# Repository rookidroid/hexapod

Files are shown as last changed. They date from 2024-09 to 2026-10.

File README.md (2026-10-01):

#  Hexapod

A family of 18-DOF, 3D-printed hexapod robots powered by an ESP32. Walk them from your phone over WiFi, or stream poses to them live from a computer. All the robots run the same firmware and gait generator. What differs is their frame, servos and dimensions.





## The Robots

| | [Nougat](./robots/nougat/) | [Mochi](./robots/mochi/) | [Macaroon](./robots/macaroon/) |
|---|---|---|---|
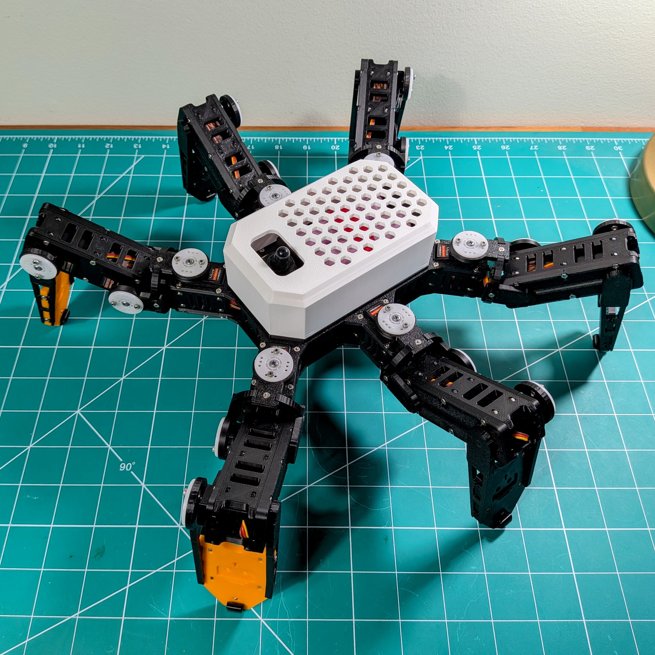
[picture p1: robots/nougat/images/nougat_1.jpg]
Nougat
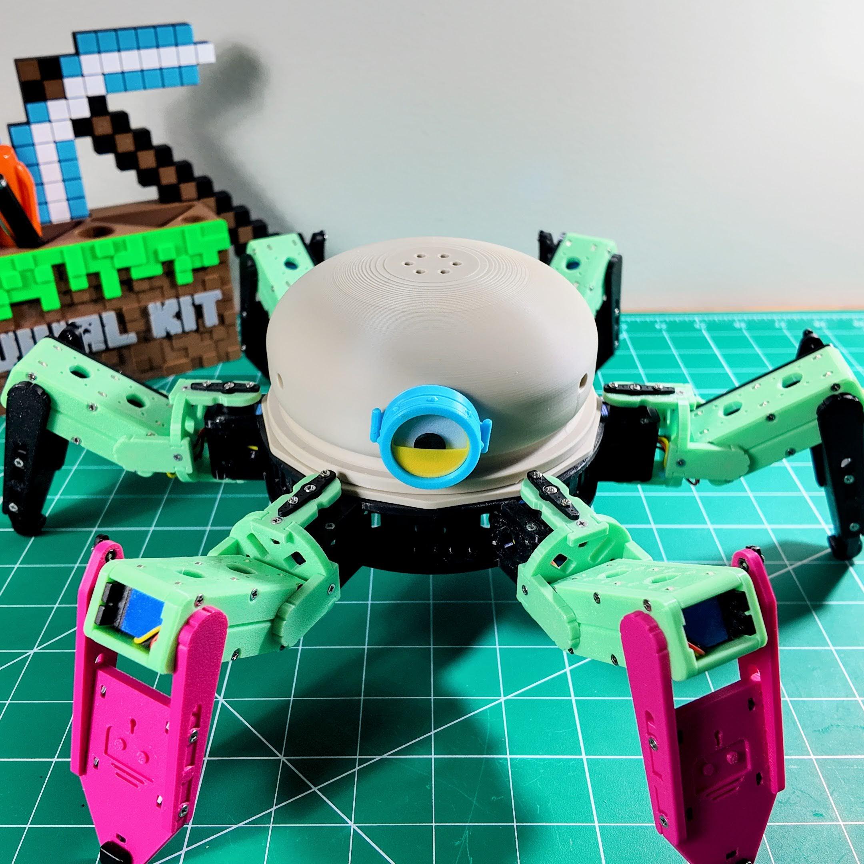
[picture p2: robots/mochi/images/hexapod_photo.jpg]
Mochi
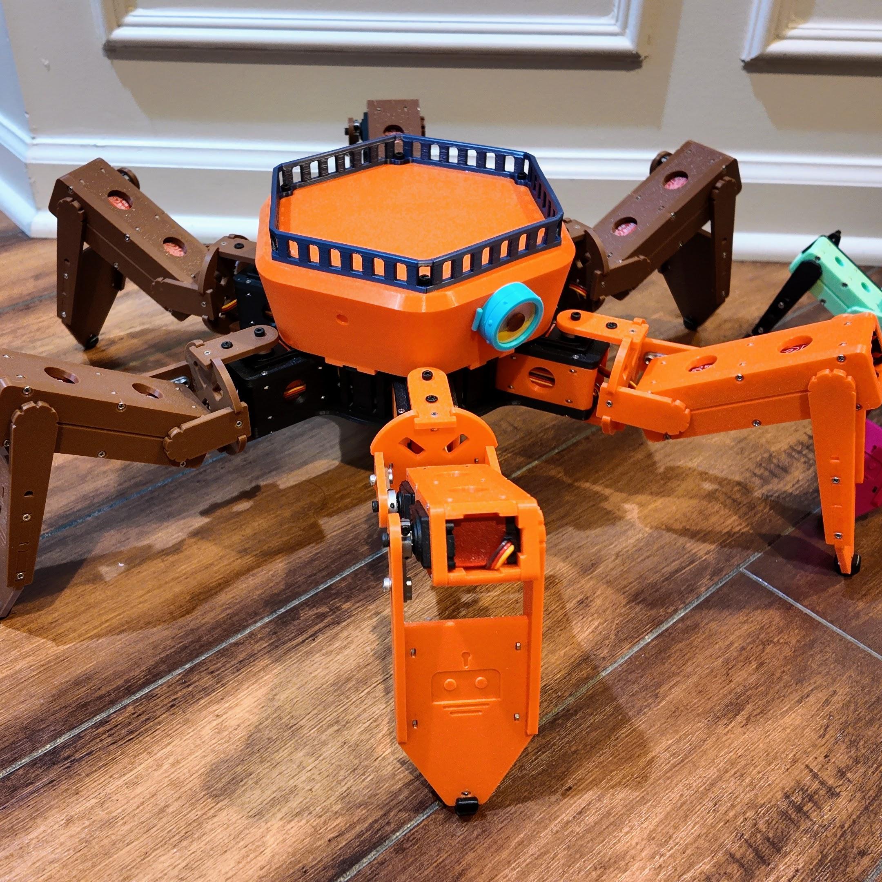
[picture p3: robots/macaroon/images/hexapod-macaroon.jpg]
Macaroon
| |  |  |  |
| **Servos** | 18 × 21G digital | 18 × MG92B micro | 18 × 25 kg digital |
| **Battery** | 2 × 18650 (2S1P) | 2 × 18650 (2S) | 4 × 18650 (2S2P) |
| **Leg links** (coxa / femur / tibia) | 38 / 54 / 97 mm | 36 / 44 / 85 mm | 62 / 76 / 132 mm |
| **Controller** | ESP32 (Pico W legacy) | ESP32 (Pico W legacy) | ESP32 |
| **Firmware define** | `ROBOT_NOUGAT` | `ROBOT_MOCHI` | `ROBOT_MACAROON` |
| **WiFi SSID** | `hexapod_nougat` | `hexapod` | `hexapod_macaroon` |

Each robot's folder has its full build guide: bill of materials, 3D-printed parts, assembly, software setup, calibration and troubleshooting.

## Repository Layout

```text
hexapod/
├── robots/                 # Hardware for each robot
│   ├── nougat/             #   README (build guide), 3d print/, images/
│   ├── mochi/
│   └── macaroon/
├── images/                 # Images shared by all robots
└── software/
    ├── hexapod_esp32/      # ESP32 firmware (Arduino sketch), shared by all robots
    │   ├── robot.h         #   Pick the robot you are building here
    │   └── src/robots/     #   Per-robot settings and generated motion tables
    ├── package_esp32.py    # Packages the ESP32 sketch into one copy per robot
    ├── hexapod_pico/       # Legacy Raspberry Pi Pico firmware (unmaintained)
    └── path_tool/          # Gait generator that produces the motion tables
        └── robots/         #   Per-robot geometry and gait parameters (JSON)
```

## Quick Start

1. Build the robot by following its guide in [`robots/`](./robots/).
2. Open [`software/hexapod_esp32/hexapod_esp32.ino`](./software/hexapod_esp32/hexapod_esp32.ino) in the Arduino IDE.
3. In [`robot.h`](./software/hexapod_esp32/robot.h), leave only your robot's `#define ROBOT_*` uncommented.
4. Upload, join the robot's WiFi network and calibrate it at `http://192.168.4.1`.

To skip step 3, download `hexapod_<robot>_<version>.zip` from the [releases](https://github.com/rookidroid/hexapod/releases): a copy of the sketch with your robot already selected. `python software/package_esp32.py` builds the same zips locally into `dist/`.

The [ESP32 firmware README](./software/hexapod_esp32/README.md) covers setup, the UDP protocol and OTA updates. The [path tool README](./software/path_tool/README.md) explains how the motion tables are generated and how to add a new robot.

## License

[GPL-3.0](./LICENSE)

## Support

- Website: [rookidroid.com](https://rookidroid.com/)
- Issues: [GitHub Issues](https://github.com/rookidroid/hexapod/issues)
- E-mail: [info@rookidroid.com](mailto:info@rookidroid.com)

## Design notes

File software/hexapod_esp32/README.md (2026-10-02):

# Hexapod ESP32 Firmware

Arduino-based firmware for the ESP32-powered hexapod robot controller, shared by every robot in the family ([Nougat](../../robots/nougat/), [Mochi](../../robots/mochi/) and [Macaroon](../../robots/macaroon/)). Supports WiFi control via UDP commands, OTA updates, and 18-servo coordination through dual PCA9685 PWM drivers.

## Features

- **WiFi Control**: Access Point mode with UDP command interface
- **Web Controller & Calibration**: Drive the robot from any browser, and adjust and save servo offsets to flash
- **Binary UDP Protocol**: Fast and efficient binary packet structure for motion control
- **18-Servo Control**: Dual PCA9685 PWM drivers (I2C) for coordinated leg movement
- **OTA Updates**: Wireless firmware updates over WiFi
- **Motion Library**: Pre-programmed gaits and movements
- **Non-blocking Motion Engine**: Gaits, streamed poses and every transition between them run from one tick-driven engine, so the web UI, OTA and failsafes stay responsive while walking
- **Event-Driven Boot**: Automatic boot sequence when client connects

## Hardware Requirements

- ESP32 Dev Module
- [Hexapod Controller Board (ESP32)](https://rookidroid.com/product/hexapod-controller-board-esp32/) - ESP32-based controller with dual PCA9685 PWM drivers
- 18× Servos (3 per leg × 6 legs)

## Dependencies

Install these libraries through Arduino Library Manager:

| Library | Purpose | Link |
|---|---|---|
| arduino-esp32 | ESP32 board support | [GitHub](https://github.com/espressif/arduino-esp32) |
| Adafruit_PWMServoDriver | PCA9685 control | [GitHub](https://github.com/adafruit/Adafruit-PWM-Servo-Driver-Library) |
| AsyncUDP | Non-blocking UDP | Included with arduino-esp32 |
| ArduinoOTA | OTA updates | Included with arduino-esp32 |
| Preferences | Calibration storage (NVS) | Included with arduino-esp32 |
| EEPROM | One-time import of older calibrations | Included with arduino-esp32 |
| WebServer | Calibration UI | Included with arduino-esp32 |

## Quick Start

### 1. Setup Arduino IDE

1. Install [Arduino IDE 2.x](https://www.arduino.cc/en/software)
2. Install ESP32 board support following [this guide](https://docs.espressif.com/projects/arduino-esp32/en/latest/installing.html)
3. Install required libraries via Library Manager (Sketch → Include Library → Manage Libraries)

### 2. Select Your Robot

Open `robot.h` and leave exactly one robot uncommented:

```cpp
// #define ROBOT_NOUGAT
// #define ROBOT_MOCHI
#define ROBOT_MACAROON
```

This picks the robot's motion tables and settings from `src/robots/<name>/`:

| Robot | `robot.h` define | WiFi SSID | `DELAY_MS` |
|---|---|---|---|
| Nougat | `ROBOT_NOUGAT` | `hexapod_nougat` | 12 |
| Mochi | `ROBOT_MOCHI` | `hexapod` | 12 |
| Macaroon | `ROBOT_MACAROON` | `hexapod_macaroon` | 25 |

`DELAY_MS` is the time between LUT frames. The frame period is now exactly
`DELAY_MS`: earlier firmware also spent ~10 ms per frame on a 100 kHz I2C bus,
so gaits play faster than before, most noticeably on Nougat and Mochi. Raise
`DELAY_MS` in `src/robots/<name>/robot_config.h` if a gait feels rushed.

With `arduino-cli`, you can pick the robot without editing the file:
`arduino-cli compile --fqbn esp32:esp32:esp32 --build-property "compiler.cpp.extra_flags=-DROBOT_MOCHI"`.

#### Per-robot packages

Each [GitHub release](https://github.com/rookidroid/hexapod/releases) also has
a ready-to-open sketch for every robot, `hexapod_<robot>_<version>.zip`. Unzip
it and open `hexapod_<robot>/hexapod_<robot>.ino`: `robot.h` is already set and
only that robot's tables are included, so you can skip this step.

To build the packages yourself, run `python software/package_esp32.py` from
the repository root. It writes a folder and a zip for every robot into `dist/`.
Name robots to package only those (`python software/package_esp32.py nougat`),
and pass `--no-zip` to write just the folders. Each package's `version.h` has
`FIRMWARE_BUILD` set to the package version (see [Firmware version](#firmware-version)).

### 3. Configure Hardware

Edit `config.h` if your wiring or WiFi password differs:

```cpp
// Servo pin mappings
static int left_legs[3][3] = { { 1, 2, 3 }, { 5, 6, 7 }, { 9, 8, 10 } };
static int right_legs[3][3] = { { 10, 9, 8 }, { 13, 14, 15 }, { 7, 6, 5 } };

// WiFi password (the SSID is set per robot in src/robots/<name>/robot_config.h)
#define APPSK "hexapod_1234"
```

### 4. Upload Firmware

1. Connect ESP32 via USB
2. Select **Tools → Board → ESP32 Dev Module**
3. Select correct COM port
4. Click **Upload**
5. Monitor Serial output (115200 baud) for IP address

### 5. Control the Robot

1. Connect to the robot's WiFi network (see the table above, password: `hexapod_1234`)
2. Robot will automatically perform boot sequence when client connects
3. Drive it from a browser at `http://192.168.4.1/` (see below), or send UDP commands to `192.168.4.1:1234`

## Drive from a Browser

The robot serves its own controller page, so a phone, tablet or laptop can drive
it with nothing installed.

1. Connect to the robot's WiFi network and open `http://192.168.4.1/`. The page
   opens on the **Drive** tab, a control panel that fills the whole window.
2. **Hold** to move, and slide your finger between zones without lifting it:
   - The **dial** (right) walks in eight directions on its inner ring. The outer
     ring does fast forward/backward at the top and bottom, and turns in place
     at the sides. The centre is Stop.
   - The **grid** (left) plays the body moves (rotate X/Y/Z, twist) and the
     climbing gait.
   - Let go and the robot settles back to standby.
3. On a keyboard, **W A S D** or the arrow keys walk (two at once for the
   diagonals), **Q** and **E** turn, and **Space** stops.
4. **Relax** cuts power to the servos so the robot sags to the ground. **Wake**,
   or any control, powers them again.

Landscape gives the Android app's layout, with the speed slider and buttons
between the two pads; in portrait they stack. Tap **Full screen** to hide the
browser bars on Android, iPad and desktop. iPhone Safari has no full-screen
mode: use **Share > Add to Home Screen** and open the page from the icon instead.

While a control is held the page resends the command every 150 ms over HTTP
(`POST /motion`), and the robot's usual 500 ms failsafe applies: if the phone
drops off the WiFi or the page goes to the background, the robot stops by
itself. The gait speed is sent with every move. Driving from the page and from
a UDP remote at the same time makes them fight over the robot; the last command
wins.

## How to Calibrate

The firmware includes a web-based calibration interface to easily adjust servo offsets without recompiling code. These offsets are saved to the ESP32's flash (NVS). Calibrations saved by older firmware in EEPROM are imported automatically on first boot.

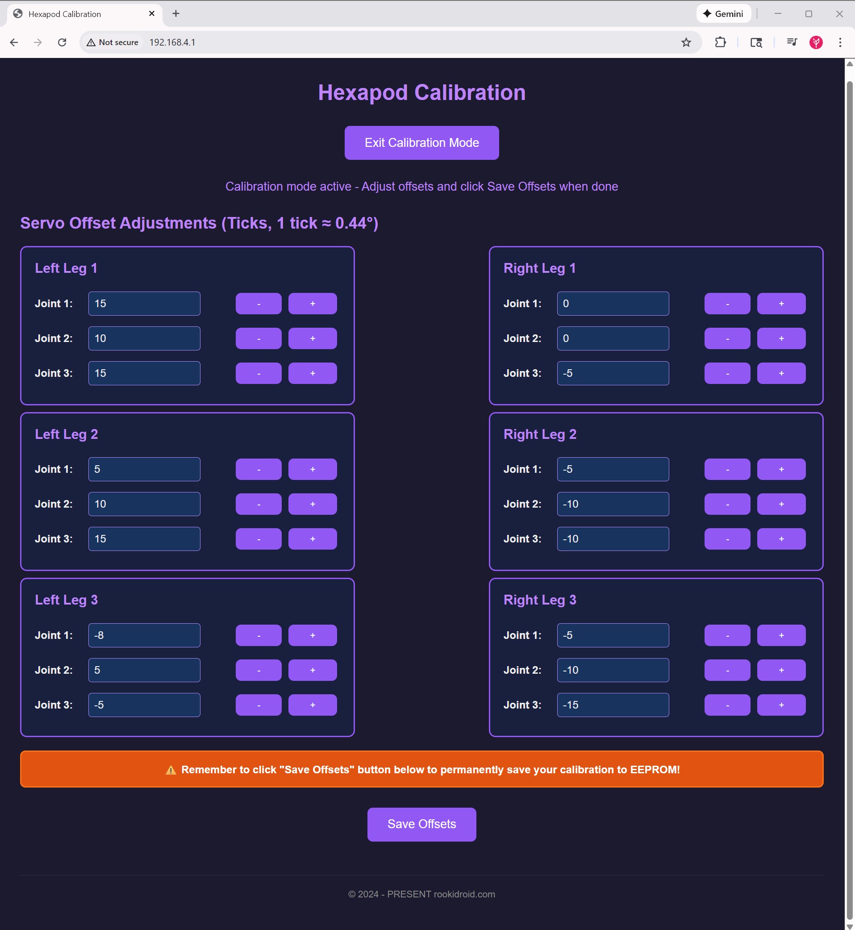
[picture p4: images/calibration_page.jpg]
Calibration Interface


### Calibration Steps:

1. Power on the hexapod and connect your device to its WiFi network (see [Select Your Robot](#2-select-your-robot)).
2. Open a web browser, navigate to `http://192.168.4.1/` and switch to the **Calibrate** tab.
3. Click the **Enter calibration** button. The robot will move to its neutral calibration posture.
4. Use the `+` and `-` buttons for each joint on the web interface to fine-tune the positions. Offsets are limited to ±100 ticks.
   - The goal is to align the legs such that the coxa (shoulder) is parallel to the body, the femur (thigh) is horizontal, and the tibia (calf) is vertical.
   - Adjust the offsets until all legs are perfectly aligned and the robot stands evenly.
5. Once satisfied with the posture, click **Save to robot**. This will permanently save the calibration values to flash.
6. Click **Exit**. The robot eases back to its standby posture.

*Note: You no longer need to manually edit offsets in `config.h`. If you wish to backup your offsets, the web interface will print the configured arrays to the Serial Monitor when you click save.*

## UDP Command Reference

Four binary packet types share port 1234. The **first byte selects the
protocol**, so the firmware dispatches on the magic number before it checks the
length (the motion and session packets are both 6 bytes).

| Magic | Packet | Size | Purpose |
|---|---|---|---|
| `0xA5` | Motion command | 6 or 7 B | Play one of the built-in gait LUTs, optionally at a set speed |
| `0xA6` | Real-time pose | 44 B | Stream raw servo positions for all 18 joints |
| `0xA7` | Session control | 6 B | Enter/leave real-time mode, relax, keep-alive |
| `0xA8` | Version query | 5 B | Ask for the firmware version; the robot replies |

All packets are little-endian and unpadded (`#pragma pack(1)`).

### Motion command (`0xA5`)

- **Byte 0**: Magic number (`0xA5`)
- **Byte 1**: Command ID (see enum below)
- **Bytes 2-5**: Sequence number (32-bit unsigned integer)
- **Byte 6** *(optional)*: Playback speed in percent (see [Motion speed](#motion-speed))

| Command ID | Action |
|---|---|
| 0 | Standby |
| 1 | Walk forward |
| 2 | Walk backward |
| 3-5 | Walk right (45°/90°/135°) |
| 6-8 | Walk left (45°/90°/135°) |
| 9-10 | Fast walk (forward/backward) |
| 11-12 | Rotate in place (left/right) |
| 13-14 | Climbing gait (forward/backward) |
| 15-17 | Body rotation (pitch/roll/yaw) |
| 18 | Body twist motion |

**Failsafe:** the robot returns to standby if no UDP packet arrives for 500 ms
(`MOTION_TIMEOUT_MS`), so keep resending the command while it should move.

Gaits change only at the start or midpoint of a cycle, and always pass through
the standby posture on the way to the next gait.

#### Motion speed

The 7-byte form appends a speed byte that sets how fast the gait LUTs play, as a
percentage of the robot's tuned frame rate (`DELAY_MS`). Values are clamped to
20-100 %; a gait at 50 % takes twice as long per cycle. The servos are still
updated every `DELAY_MS`: below 100 % the firmware blends between adjacent LUT
frames, so slow gaits stay smooth instead of stepping from frame to frame. `0`
leaves the speed unchanged, and the 6-byte form never
touches it. Only gait playback follows the speed: the transitions between gaits
keep their pace so the robot still stops promptly.

The speed starts at **60 %** after boot (`MOTION_SPEED_DEFAULT_PCT` in
`config.h`), so clients that only send the 6-byte form walk at 60 % unless the
speed is raised. It can also be set from the **Gait speed** slider on the web
page at `http://192.168.4.1/`; a client sending 7-byte packets, such as the
[arcade remote](https://github.com/rookidroid/remote-arcade), overrides it with
every packet. The setting is not saved across reboots.

#### Example (Python)

```python
import socket
import struct

# 0xA5 (magic), 1 (Walk forward), 0 (sequence), 60 (speed %)
packet = struct.pack("<BBIB", 0xA5, 1, 0, 60)
sock = socket.socket(socket.AF_INET, socket.SOCK_DGRAM)
sock.sendto(packet, ("192.168.4.1", 1234))
```

### Real-time pose (`0xA6`)

Streams servo positions directly, bypassing the motion LUTs. Used by the
[hexapod-robot-simulator](https://github.com/rookidroid/hexapod-robot-simulator)
to drive the robot live, from a single joint up to a whole-body pose.

| Offset | Type | Field | Notes |
|---|---|---|---|
| 0 | `uint8` | magic | `0xA6` |
| 1 | `uint8` | flags | bit 0: snap immediately instead of obeying the slew limit |
| 2 | `uint16` | max_step | Per-joint slew limit in ticks per 20 ms cycle (0 = default, 8) |
| 4 | `uint32` | seq_num | Sequence number |
| 8 | `int16[6][3]` | ticks | Servo ticks, leg-major |

Leg order matches the motion LUTs: right front, right middle, right back, left
front, left middle, left back. Joint order is coxa, femur, tibia. Ticks use the
same scale as the LUTs (`SERVOMIN` 102 … `SERVOMAX` 512, mid 307), before
calibration: the saved per-joint offset is added on the robot, exactly as it is
for LUT playback. Ticks are clamped on arrival to the window that stays within
`SERVOMIN`…`SERVOMAX` after that offset, so calibration never costs a joint any
travel.

Receiving a pose packet implicitly enters real-time mode from whatever posture
the robot holds, even mid-gait. Each control cycle every joint moves toward its
target by at most `max_step` ticks, so a large jump becomes a controlled slew
rather than a step input to 18 servos at once.

**Ordering:** UDP can reorder packets. A pose whose `seq_num` is up to 63 behind
the newest one received is dropped. A bigger step back is taken as a client
restart and accepted. The window resets on `RT_ENTER`.

**Failsafe:** if no packet arrives for 1 s the robot eases back to standby and
returns to LUT control. Send a keep-alive (below) while idle.

### Session control (`0xA7`)

| Offset | Type | Field |
|---|---|---|
| 0 | `uint8` | magic (`0xA7`) |
| 1 | `uint8` | action |
| 2 | `uint32` | seq_num |

| Action | Name | Effect |
|---|---|---|
| 0 | Exit | Leave real-time mode, resume LUT playback from standby |
| 1 | Enter | Enter real-time mode, holding the current posture |
| 2 | Relax | Disable both PWM drivers so the servos go limp; any motion command, pose or Enter wakes them |
| 3 | Ping | Keep-alive; resets the failsafe timer |

Sending a motion command (`0xA5`) also leaves real-time mode, so the two control
styles cannot fight over the servos.

#### Example (Python)

```python
import socket
import struct

sock = socket.socket(socket.AF_INET, socket.SOCK_DGRAM)
addr = ("192.168.4.1", 1234)

# Enter real-time mode
sock.sendto(struct.pack("<BBI", 0xA7, 1, 0), addr)

# Hold the standby posture (matches lut_standby)
ticks = [307, 239, 273] * 3 + [307, 375, 341] * 3
sock.sendto(struct.pack("<BBHI" + "h" * 18, 0xA6, 0, 8, 1, *ticks), addr)
```

### Version query (`0xA8`)

The only packet the robot answers. The reply goes back to the address and port
the query came from.

| Offset | Type | Field |
|---|---|---|
| 0 | `uint8` | magic (`0xA8`) |
| 1 | `uint32` | seq_num |

Reply (9-byte header, then the build tag):

| Offset | Type | Field | Notes |
|---|---|---|---|
| 0 | `uint8` | magic | `0xA8` |
| 1 | `uint32` | seq_num | Copied from the query |
| 5 | `uint8` | protocol | `PROTOCOL_VERSION` in `protocol.h` |
| 6 | `uint8` | major | Firmware version, see [Firmware version](#firmware-version) |
| 7 | `uint8` | minor | |
| 8 | `uint8` | patch | |
| 9 | `char[]` | build | `FIRMWARE_BUILD`, UTF-8, unterminated; runs to the end of the datagram |

A query is not control input: it does not reset the motion or real-time
failsafe timers and does not disable OTA. Firmware older than this packet does
not answer, so use a receive timeout and treat silence as "unknown version".

```python
import socket
import struct

sock = socket.socket(socket.AF_INET, socket.SOCK_DGRAM)
sock.settimeout(0.5)
sock.sendto(struct.pack("<BI", 0xA8, 7), ("192.168.4.1", 1234))

data, _ = sock.recvfrom(64)
magic, seq, protocol, major, minor, patch = struct.unpack_from("<BIBBBB", data)
print(f"firmware {major}.{minor}.{patch} ({data[9:].decode()}), protocol {protocol}")
```

> **Note:** packets are not echoed or logged to serial by default. Build with
> `HEXAPOD_DEBUG` set to 1 in `config.h` to log and echo motion and session
> packets. Pose packets are never logged: at 50 Hz the logging would saturate
> the serial port and stall the UDP task.

## Robot Config (HTTP)

`GET http://192.168.4.1/robot_config` describes the robot the firmware was built
for, so a client such as [Hexapod Link](https://github.com/rookidroid/hexapod-link)
can model and drive it without its own copy of every robot's config:

```json
{
  "protocol": 1,
  "firmware": {"version": "3.2.0", "build": "v3.2.0"},
  "name": "nougat",
  "ssid": "hexapod_nougat",
  "delay_ms": 12,
  "servo": {"min": 102, "mid": 307, "max": 512},
  "speed": {"min": 20, "max": 100, "default": 60, "current": 60},
  "commands": ["standby", "walk0", "walk180", "...", "twist"],
  "geometry": {"name": "nougat", "label": "Nougat", "legMountX": ["..."], "...": "..."}
}
```

- `protocol` is `PROTOCOL_VERSION` in `protocol.h`.
- `firmware` is the [firmware version](#firmware-version) and build tag.
- `commands` lists the motion names in `RobotCommand` order: a name's index is
  the command ID for a `0xA5` packet.
- `geometry` is the robot's `software/path_tool/robots/<name>.json` (leg mounts,
  link lengths, `legScale`, postures, gait radii and joint limits), compiled in
  from `src/robots/<name>/robot_geometry.h`. After editing the JSON, refresh the
  header with `python generate_motion.py <name>` (or `--geometry-only` to leave
  the LUTs alone).

The other HTTP routes back the web page's drive and calibration tabs:

| Route | Method | Purpose |
| --- | --- | --- |
| `/enter_calibration` | GET | Enter calibration mode; returns the offsets |
| `/exit_calibration` | GET | Leave calibration mode |
| `/get_offsets` | GET | `{"left":[[..],[..],[..]],"right":[[..],[..],[..]]}` |
| `/set_offsets` | POST | Apply offsets (same JSON; calibration mode only, each clamped to +/-100) |
| `/save_offsets` | POST | Save the offsets to flash |
| `/get_speed` | GET | `{"speed":N}` |
| `/set_speed?pct=N` | POST | Set the LUT playback speed; returns `{"speed":N}` |
| `/motion?id=N[&pct=S]` | POST | Play motion `N` (index into `commands`), optionally at speed `S`; same effect and 500 ms failsafe as a `0xA5` packet. Returns `{"motion":N,"speed":S}`; 409 in calibration mode |
| `/relax` | POST | Cut PWM drive so the servos go limp, like session action Relax; 409 in calibration mode |

## Firmware Version

`version.h` holds the firmware version, `FIRMWARE_VERSION_MAJOR`, `_MINOR` and
`_PATCH`. Bump it by hand when releasing: major for changes that break clients
or saved calibrations, minor for new features, patch for fixes and tuning.
`FIRMWARE_BUILD` is a free-form tag, `"dev"` in the repository; the release
packages set it to the package version (the git tag, or `git describe`).

The version is printed on the serial port at boot, returned by the
[version query](#version-query-0xa8) and included in `GET /robot_config`.

## OTA Updates

After initial USB upload, use OTA for wireless updates:

1. Power on robot and connect to its WiFi
2. In Arduino IDE: **Tools → Port → Network Ports**, then select `hexapod-<robot>` (e.g. `hexapod-macaroon`)
3. Upload as normal. The servos go limp while the new firmware is written
4. Note: OTA is disabled after the first motion command or real-time session (reboot to re-enable)

OTA has no password by default, so anyone who joins the robot's access point
can flash it. Define `OTA_PASSWORD` in `config.h` to require one.

## File Structure

```text
hexapod_esp32/
├── hexapod_esp32.ino    # setup() / loop() and the shared system state
├── motion_control.ino   # PWM drivers, motion engine, every write to a servo
├── realtime.ino         # Real-time pose streaming and its slew limiter
├── network.ino          # WiFi AP, OTA, UDP endpoint and packet parsing
├── calibration.ino      # Servo offsets loaded from / saved to flash (NVS)
├── web_ui.ino           # HTTP routes: drive, calibration, speed, /robot_config
├── hexapod.h            # Shared state and module interfaces
├── protocol.h           # UDP packet layouts and magic numbers
├── version.h            # Firmware version and build tag
├── web_page.h           # Drive and calibration page served from flash
├── config.h             # Hardware config, pin mappings, calibration
├── robot.h              # Selects the robot the firmware is built for
├── motion.h             # Includes the selected robot's motion tables
├── robot_geometry.h     # Includes the selected robot's geometry JSON
├── src/robots/<name>/
│   ├── robot_config.h   # Robot-specific settings (WiFi SSID, DELAY_MS)
│   ├── robot_geometry.h # Geometry served at /robot_config (generated by path_tool)
│   └── motion.h         # Motion lookup tables (generated by path_tool)
└── README.md            # This file
```

[`../package_esp32.py`](../package_esp32.py) copies this sketch into one
`hexapod_<robot>/` sketch per robot (see [Per-robot packages](#per-robot-packages)).

The `.ino` files are Arduino sketch tabs: the build concatenates them into one
translation unit, so the `static` tables in `config.h` and `motion.h` exist once
and every module sees the same calibration offsets. Types used in function
signatures belong in `hexapod.h`, because the build hoists each tab's function
prototypes above that tab's own declarations.

Only the main loop writes to the servos. The UDP task records requests
(`next_motion_idx`, `realtime_mode`, `relax_requested`, the streamed pose) and
`serviceMotionEngine()` acts on them at its next tick, starting every transition
from `pose_current`, the pose last written to the servos.

## Configuration Parameters

Key constants in `config.h`:

```cpp
// Servo timing (DELAY_MS, the delay between LUT steps, is per robot in robot_config.h)
const uint16_t SERVO_INIT_DELAY_MS = 50;    // Boot sequence delay
const uint8_t TRANSITION_TICK_STEP = 6;      // Transition smoothness
#define MOTION_TIMEOUT_MS 500                // LUT failsafe
#define REALTIME_TIMEOUT_MS 1000             // Real-time failsafe

// Hardware
const uint8_t LEFT_PWM_ADDRESS = 0x40;       // Left PCA9685 I2C address
const uint8_t RIGHT_PWM_ADDRESS = 0x41;      // Right PCA9685 I2C address
const uint8_t LEFT_PWM_ENABLE_PIN = 19;      // Left driver enable (active LOW)
const uint8_t RIGHT_PWM_ENABLE_PIN = 26;     // Right driver enable (active LOW)
const uint32_t I2C_CLOCK_HZ = 400000;        // I2C bus speed
const uint32_t PCA9685_OSC_HZ = 25000000;    // Tune if servo angles are off

// Calibration
const int CALIBRATION_MAX_OFFSET = 100;      // Largest accepted offset (ticks)
```

## Troubleshooting

### WiFi connection issues

- Verify the SSID in `src/robots/<name>/robot_config.h` and the password in `config.h`
- Check serial monitor for IP address (192.168.4.1 default)
- Ensure client device supports 2.4GHz WiFi

### Servos not moving

- Check PWM driver I2C addresses match hardware (0x40, 0x41)
- Verify enable pins are connected correctly (active LOW)
- Confirm servo pin mappings in `config.h`
- Test individual servos with `posture_calibration()` function

### OTA not visible

- OTA only works before first motion command
- Reboot robot to re-enable OTA
- Ensure connected to robot's WiFi network
- Check firewall settings on upload computer

## Adding Custom Motions

1. Add the path to `gen_luts()` in [`../path_tool/generate_motion.py`](../path_tool/generate_motion.py) so it is generated for every robot
2. Regenerate the LUTs with `python generate_motion.py --all`, which rewrites each `src/robots/<name>/motion.h`
3. Add a command ID before `CMD_COUNT` in `protocol.h`, then the matching entry at the same position in `motion_config[]` in `motion_control.ino` (a `static_assert` checks the counts match):

```cpp
const MotionConfig motion_config[] = {
  // ... existing motions ...
  { "mymotion", lut_mymotion_length, lut_mymotion }
};
```

## License

Copyright (C) 2024 - PRESENT rookidroid.com

## Support

- Website: [rookidroid.com](https://rookidroid.com/)
- Email: [info@rookidroid.com](mailto:info@rookidroid.com)

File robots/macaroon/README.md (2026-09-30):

#  Hexapod Macaroon

An 18-DOF, 3D-printed hexapod robot powered by an ESP32 — walk it from your phone over WiFi, or stream poses to it live from a computer.





hexapod_photo1
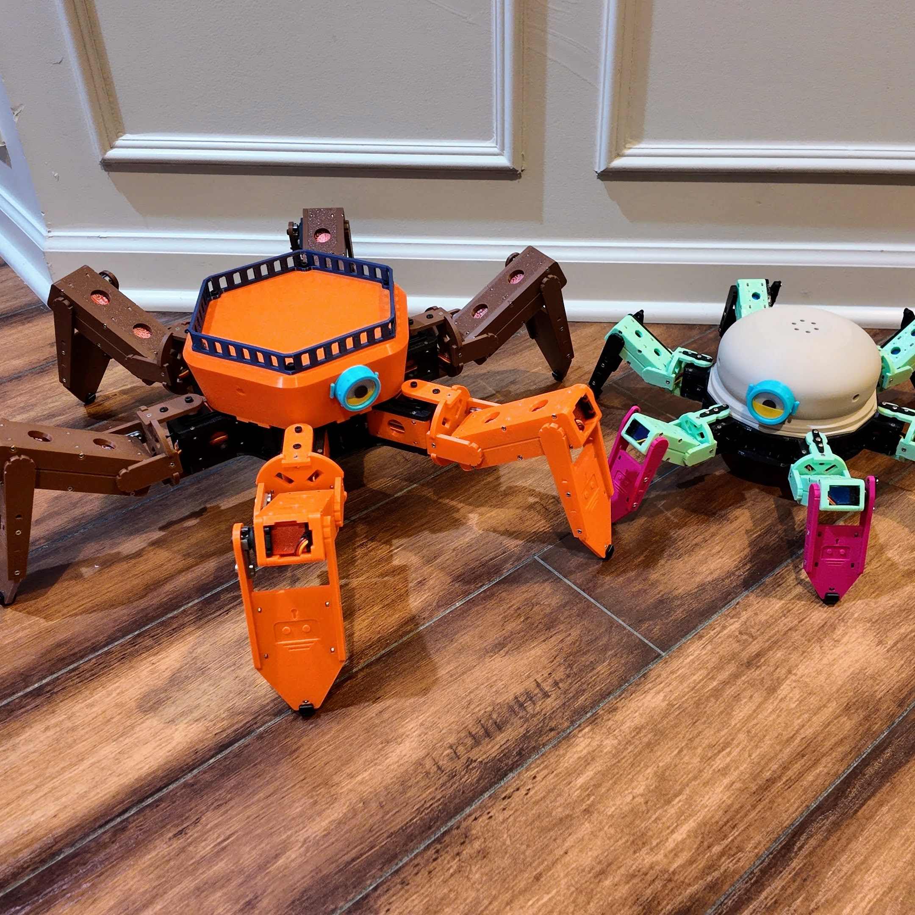
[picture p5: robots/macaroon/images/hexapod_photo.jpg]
hexapod_photo2


**Jump to:** [Bill of Materials](#bill-of-materials-bom) · [Assembly](#assembly-instructions) · [Software Setup](#software-setup) · [Control Interface](#control-interface) · [Calibration](#calibration-guide) · [Troubleshooting](#troubleshooting)

<details>
<summary><b>Table of Contents</b></summary>

- [Introduction](#introduction)
  - [Specifications](#specifications)
  - [What You'll Build](#what-youll-build)
  - [Skill Level](#skill-level)
- [Bill of Materials (BOM)](#bill-of-materials-bom)
  - [Electronics Components](#electronics-components)
  - [Connection Diagram](#connection-diagram)
- [Assembly Instructions](#assembly-instructions)
  - [Safety Notes](#safety-notes)
  - [Step 1: 3D-Printed Parts](#step-1-3d-printed-parts)
  - [Step 2: Hardware Components](#step-2-hardware-components)
- [Software Setup](#software-setup)
  - [Prerequisites](#prerequisites)
  - [Step-by-Step Installation](#step-by-step-installation)
  - [Repository Layout](#repository-layout)
  - [Project File Structure](#project-file-structure)
  - [Regenerating the Motion Tables](#regenerating-the-motion-tables)
  - [Control Interface](#control-interface)
  - [Over-The-Air (OTA) Updates](#over-the-air-ota-updates)
  - [Troubleshooting](#troubleshooting)
  - [Android App](#android-app)
  - [Desktop Control Software](#desktop-control-software)
- [Calibration Guide](#calibration-guide)
- [Related Projects](#related-projects)
- [Contributing](#contributing)
- [License](#license)
- [Support](#support)

</details>

## Introduction

This agile, 3D-printed hexapod robot is designed to work with an ESP32, providing flexibility and enhanced performance. Equipped with stronger 25kg servos, it offers a range of advanced features, including:

- **Robust, durable structure**: 3D-printed parts designed for strength and easy assembly
- **WiFi-enabled remote control**: Control your hexapod wirelessly from your smartphone or computer
- **Smooth, agile movement**: Advanced motion algorithms for natural walking patterns
- **Web-based calibration interface**: Easy servo calibration through your browser with real-time adjustment
- **Real-time pose streaming**: Drive all 18 servos live from a computer over UDP
- **Over-the-air (OTA) firmware updates**: Update firmware without cables for easy maintenance

### Specifications

| Item | Value |
| ---- | ----- |
| **Degrees of freedom** | 18 (6 legs × 3 joints: coxa, femur, tibia) |
| **Actuators** | 18 × 25 kg digital servos, 180° travel, 8.4 V capable |
| **Controller** | ESP32 with dual PCA9685 PWM drivers (I²C `0x40` / `0x41`) |
| **Power** | 4 × 18650 Li-ion in 2S2P — 7.4 V nominal, 8.4 V fully charged |
| **Connectivity** | 2.4 GHz WiFi Access Point (the robot hosts its own network) |
| **Control** | Binary UDP protocol on `192.168.4.1:1234`, plus a web UI on `http://192.168.4.1` |
| **Real-time streaming** | All 18 joints at 50 Hz, with per-joint slew limiting and a 1 s failsafe |
| **Firmware updates** | USB or over-the-air (OTA) over WiFi |
| **Resolution** | ~0.44° per servo tick (410 ticks over 180°) |

### What You'll Build

This project will guide you through building a fully functional hexapod robot with 18 degrees of freedom (3 joints per leg × 6 legs). The complete build typically takes 8-12 hours, including 3D printing, assembly, and calibration.

### Skill Level

- **Beginner-Intermediate**: Mechanical assembly skills required. No soldering is needed with the pre-assembled [Controller Board](https://rookidroid.com/product/hexapod-controller-board-macaroon-esp32/) — the servos, switch and battery holder plug straight in.
- **Tools needed**: Hex key set and a small screwdriver
- **Only if you build your own wiring harness**: soldering iron, wire cutters/strippers

## Bill of Materials (BOM)

### Electronics Components

| Name | Thumbnail | Required # | Specifications | Note |
| --- | --- | --- | --- | --- |
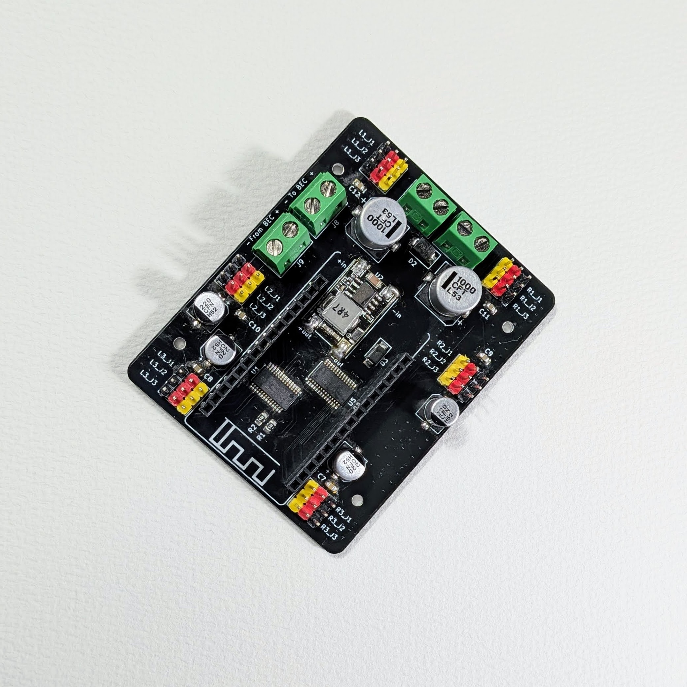
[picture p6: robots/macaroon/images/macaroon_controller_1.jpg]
controller_board
| Controller Board |  | 1 | ESP32 with dual PCA9685 drivers; servos are powered directly from the batteries | Purchase [Controller Board](https://rookidroid.com/product/hexapod-controller-board-macaroon-esp32/). |
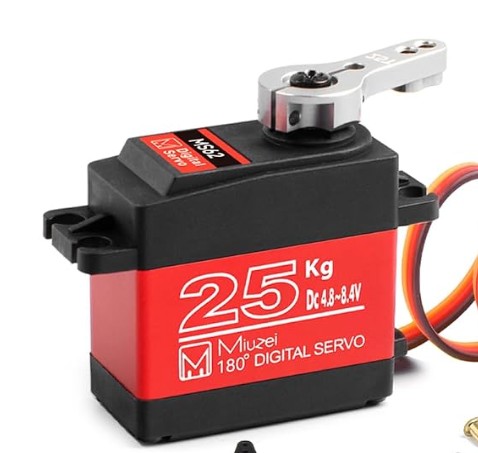
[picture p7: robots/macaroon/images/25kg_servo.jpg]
25kg_servo
| 25 kg Servo |  | 18 | 180° rotation, 25 kg class | **Support 8.4v supply voltage**. Ensure all servos are from the same batch for consistency |
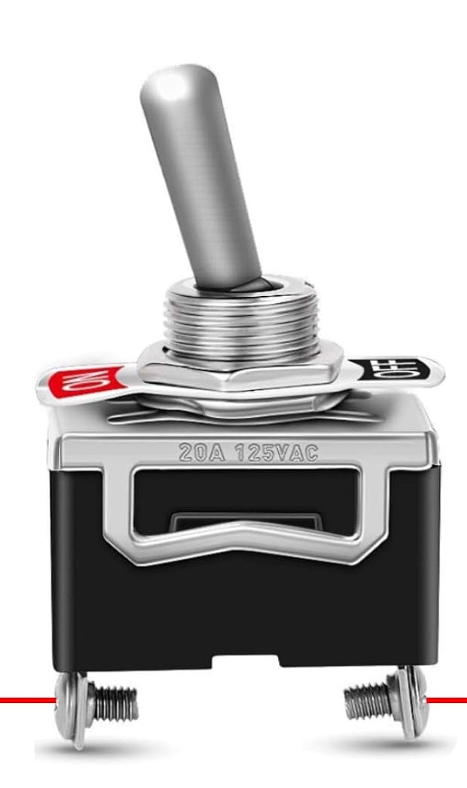
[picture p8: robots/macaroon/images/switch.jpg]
switch
| Toggle Switch |  | 1 | SPST, 12 mm diameter |  Purchase together with the [Controller Board](https://rookidroid.com/product/hexapod-controller-board-macaroon-esp32/). |
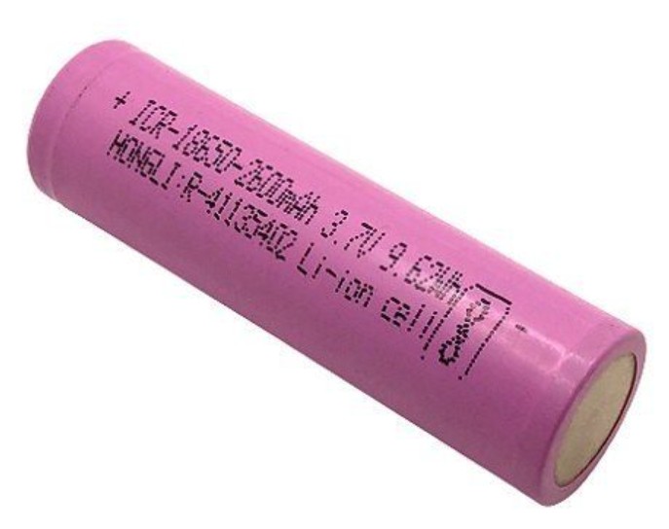
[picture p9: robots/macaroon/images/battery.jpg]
battery
| 18650 Battery |  | 4 | 3.7V Li-ion, 2000mAh+ recommended | **Use protected batteries for safety** |
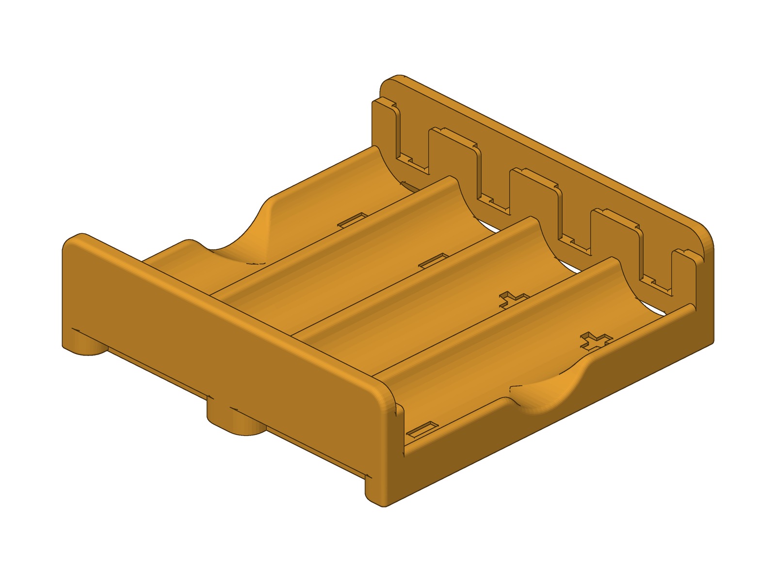
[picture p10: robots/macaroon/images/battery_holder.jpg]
battery_holder
| 18650 Battery Holder |  | 1 | 4-cell (2S2P) holder with wire leads | A 3D-printable holder is available [here](https://rookidroid.com/product/18650-battery-holder/), or purchase together with the [Controller Board](https://rookidroid.com/product/hexapod-controller-board-macaroon-esp32/). |

### Connection Diagram

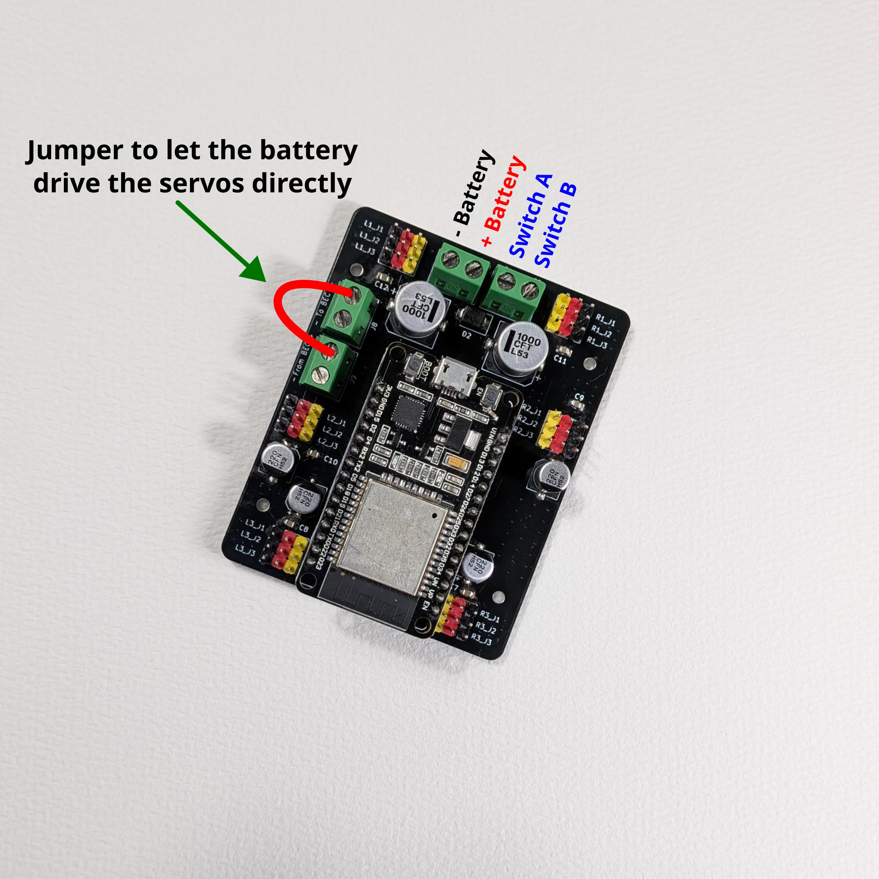
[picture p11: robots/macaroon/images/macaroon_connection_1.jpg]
diagram_1


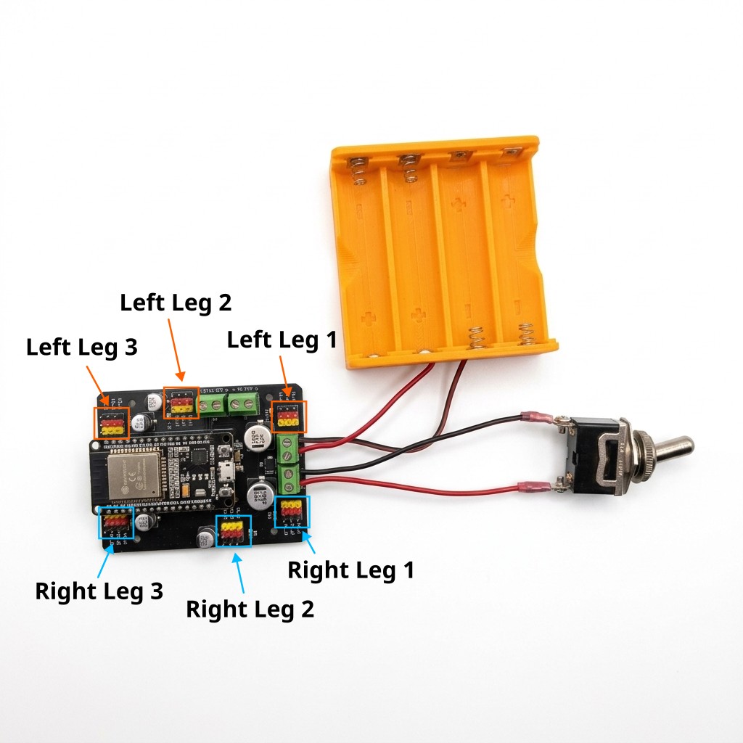
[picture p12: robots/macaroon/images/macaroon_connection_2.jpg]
diagram_2


## Assembly Instructions

### Overview

Follow these steps in order for the best results:

1. **3D Print all parts** (see parts list below)
2. **Prepare hardware** (organize screws, nuts, bearings, and pins)
3. **Assemble body** (install servos and controller)
4. **Build legs** (joint → leg → foot for each leg)
5. **Attach legs to body**
6. **Wire and test** (connect servos, upload firmware, calibrate)

**⚠️ Important:** Do NOT tighten the servo horn screws during assembly! Leave them loose to allow for rotation. You'll tighten them properly during the calibration process after adjusting each servo to its correct neutral position.

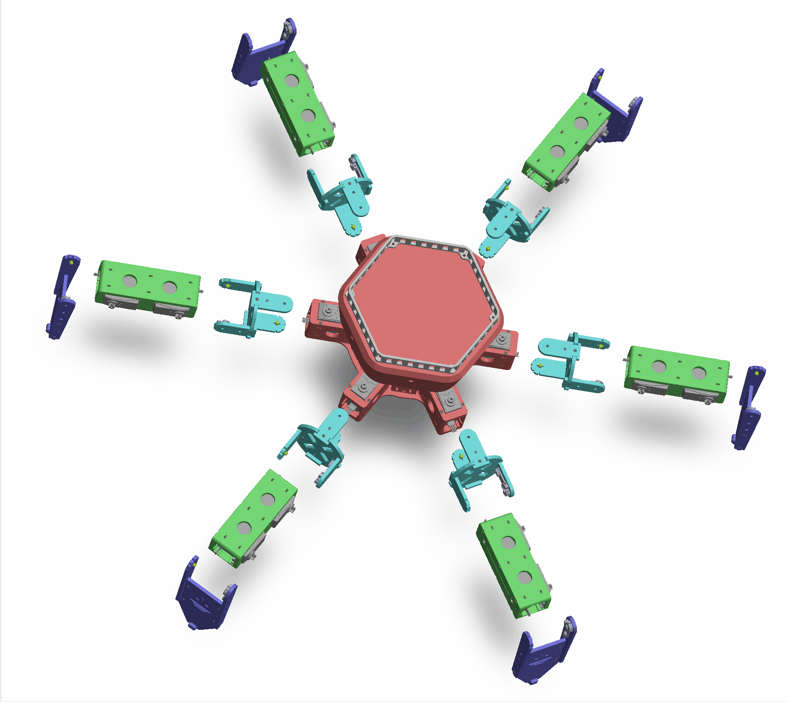
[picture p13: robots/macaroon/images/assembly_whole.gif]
whole_assembly


### Safety Notes

- **Check battery polarity twice** before the first power-up — reversed polarity will destroy the controller board.
- **Keep fingers clear of the joints when powered.** Eighteen 25 kg servos have enough torque to pinch hard.
- **Support the robot on the first power-on.** It runs its stand-up sequence automatically as soon as a client joins its WiFi network, so hold it or stand it on a box with the legs free.
- **Treat the Li-ion pack with respect**: protected cells only, a proper 2S charger, and never charge unattended.
- If a leg moves somewhere unexpected, **cut power with the toggle switch** rather than trying to hold the leg back.

### Step 1: 3D-Printed Parts

All STL files are located in the [`3d print`](./3d%20print/) folder. Ready-to-print Bambu Studio projects (`bambu_studio_*.3mf`) are included as well.

**Print Settings Recommendations:**

- Layer height: 0.2 mm
- Infill: 20-30%
- Material: PLA or PETG for the structure, TPU for the foot tips
- Supports: Required for some parts (check STL orientation)
- Print one leg's worth of parts first and test-fit it before committing to all six

#### Step 1.1: Body Components (x1 complete body)

**Assembly Tips:**

- Install servos before closing the body
- Route wires neatly to avoid pinching
- Test fit all parts before final assembly

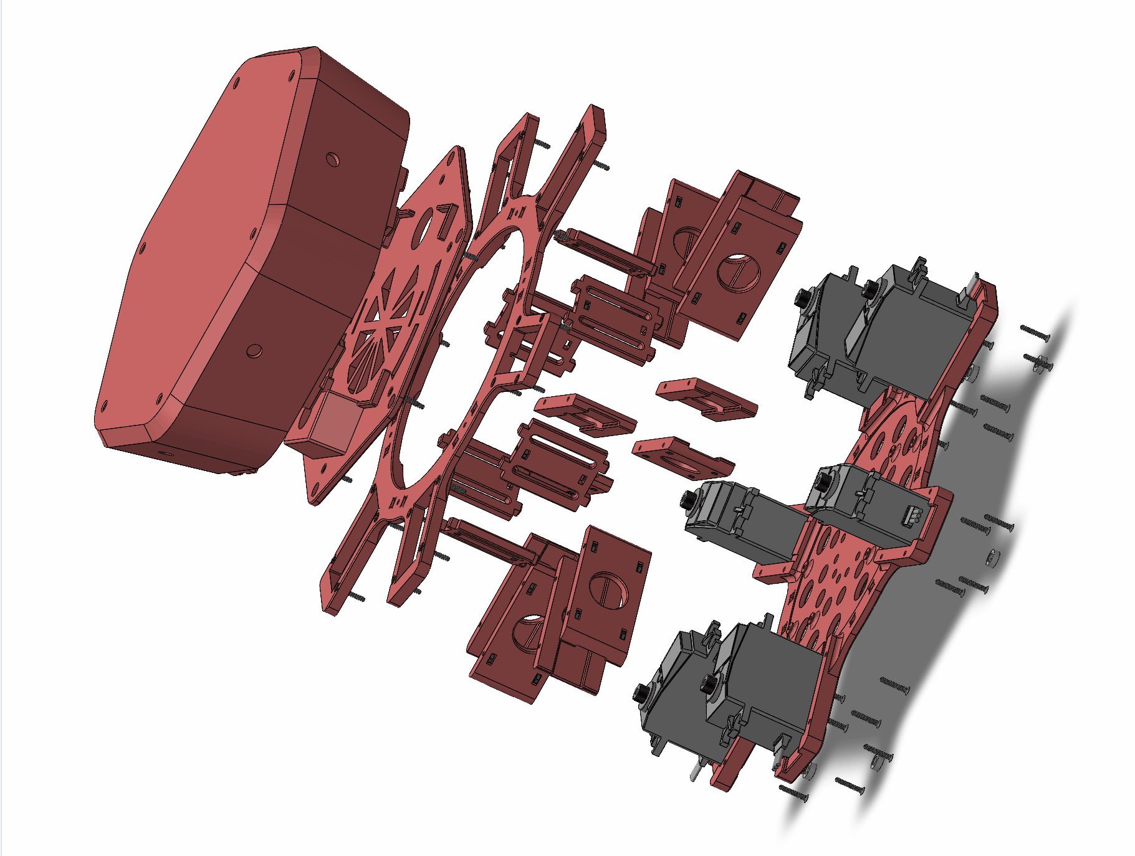
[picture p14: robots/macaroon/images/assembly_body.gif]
body_assembly


| Filename | Thumbnail | Required # |
| --- | --- | --- |
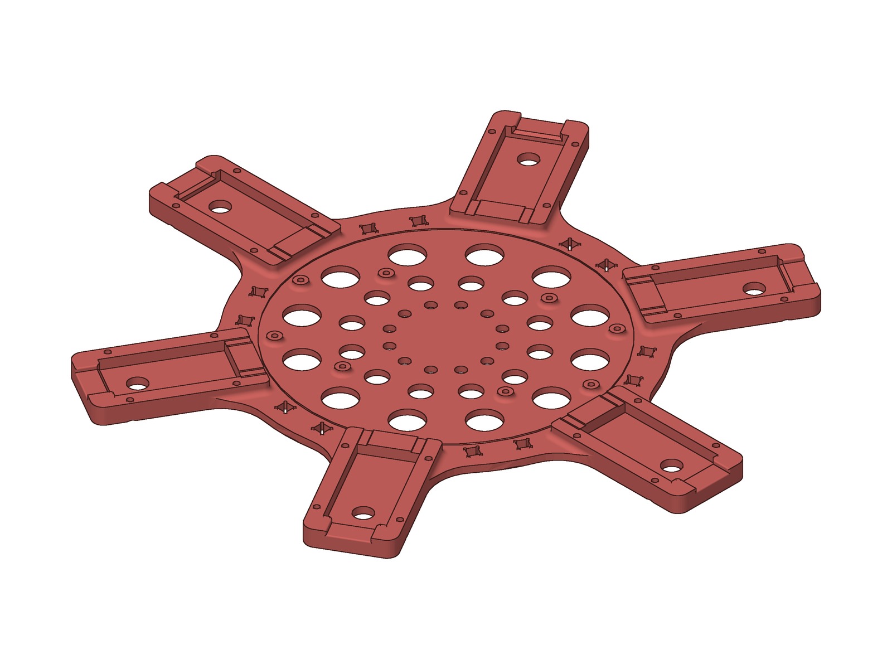
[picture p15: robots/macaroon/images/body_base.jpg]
body_base
| body_base |  | 1 |
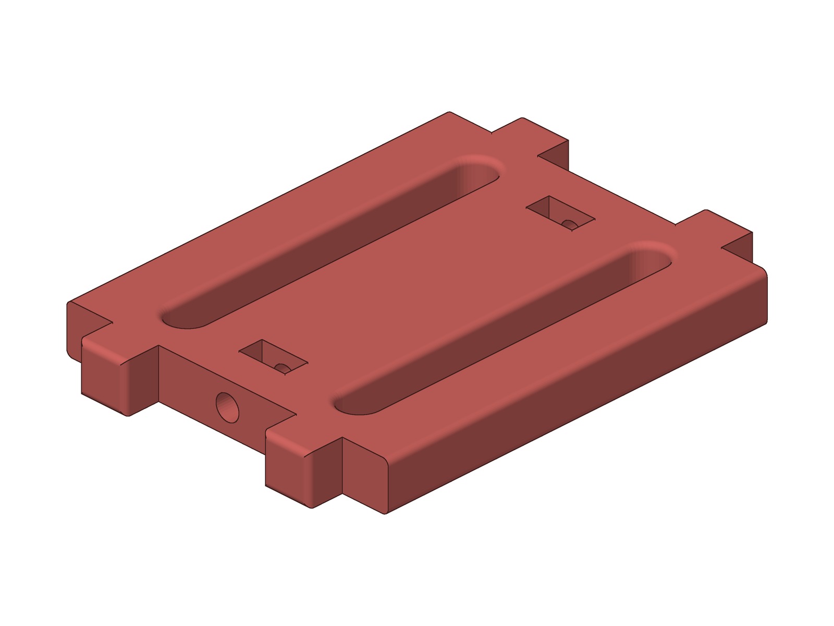
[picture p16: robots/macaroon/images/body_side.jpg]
body_side
| body_side |  | 6 |
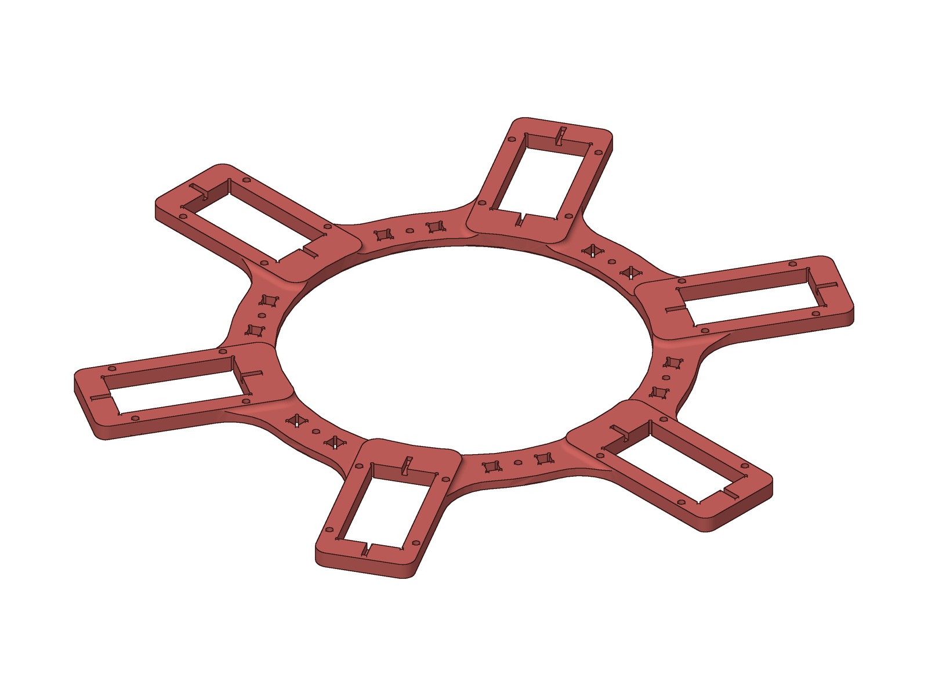
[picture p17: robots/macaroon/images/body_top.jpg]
body_top
| body_top |  | 1 |
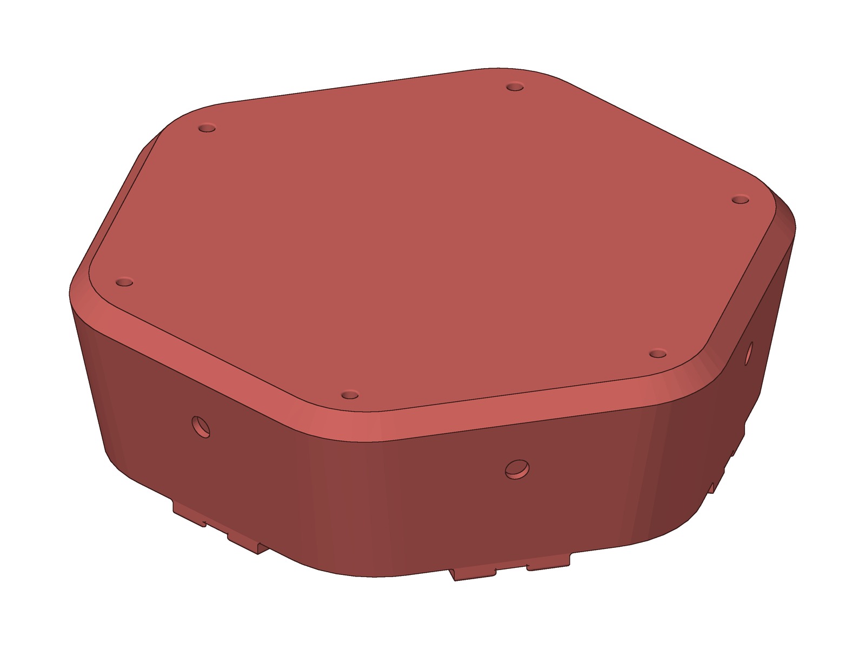
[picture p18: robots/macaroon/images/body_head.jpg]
body_head
| body_head |  | 1 |
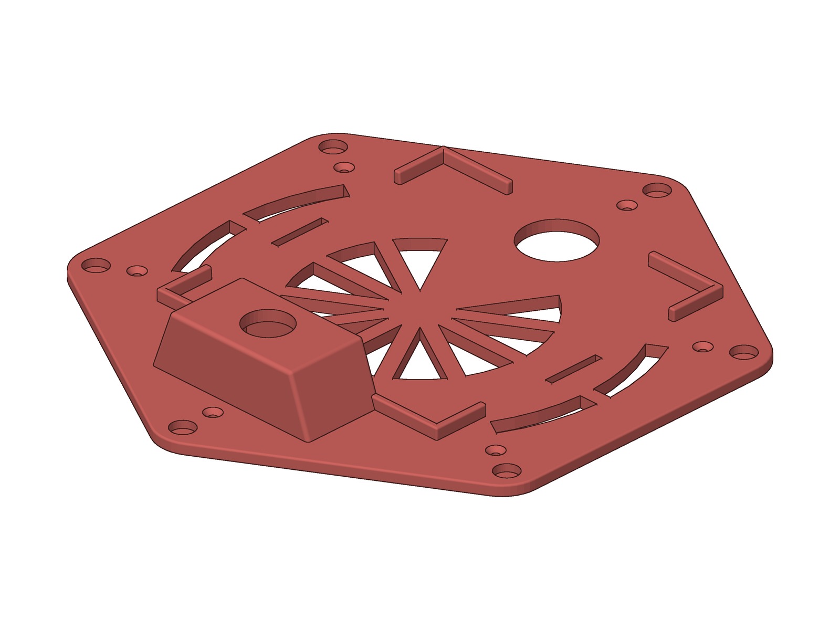
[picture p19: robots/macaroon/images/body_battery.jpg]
body_battery
| body_battery |  | 1 |
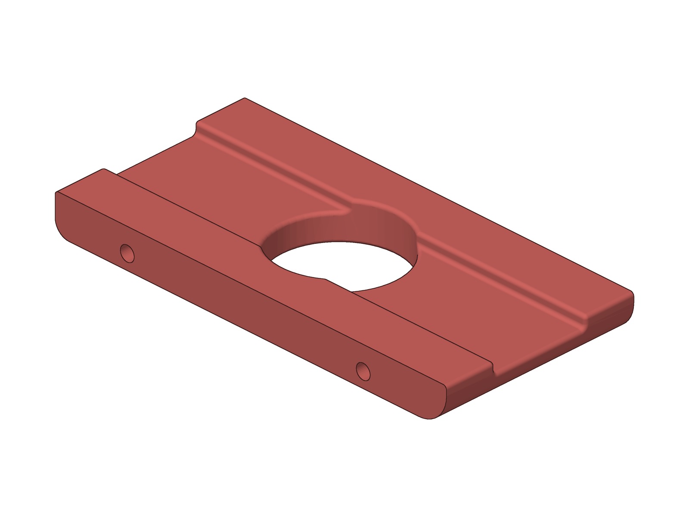
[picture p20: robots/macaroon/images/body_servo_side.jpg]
body_servo_side
| body_servo_side |  | 12 |
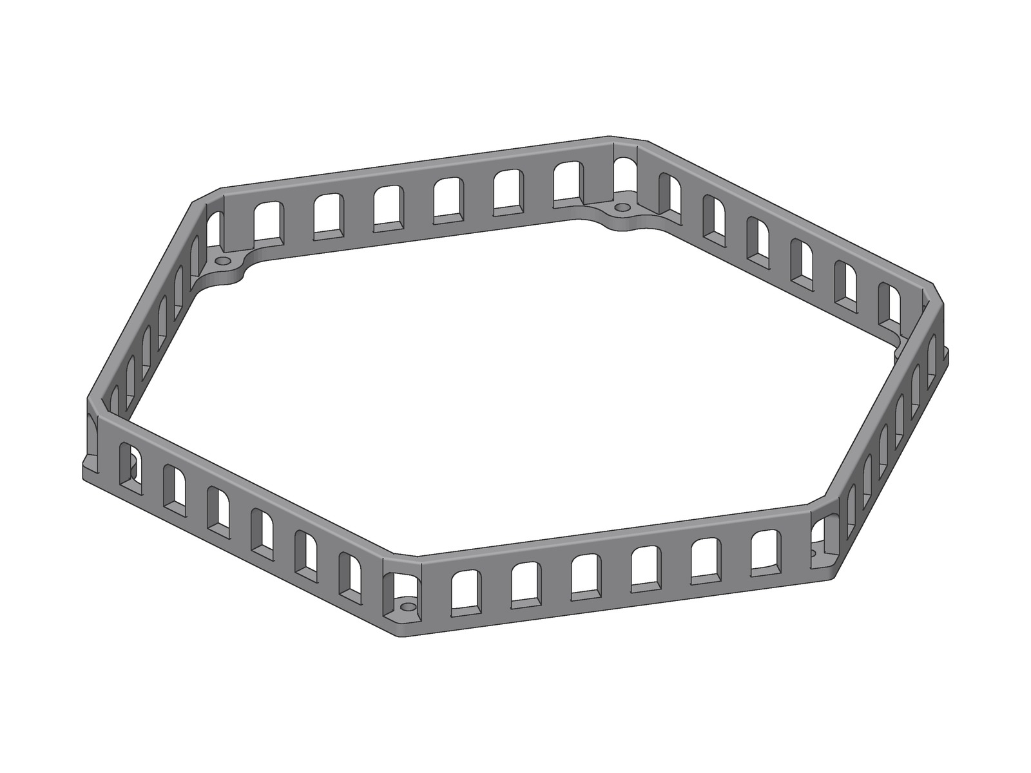
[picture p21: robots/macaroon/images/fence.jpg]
fence
| fence |  | 1 (optional) |

#### Step 1.2: Joint Components (x6 total: 3 standard + 3 mirrored)

**Important:** Pay attention to joint orientation! Three legs use standard joints, three use mirrored joints.

- **Left side legs**: Use mirrored joints
- **Right side legs**: Use standard joints

_Refer to the fully assembled robot images for correct joint orientations_

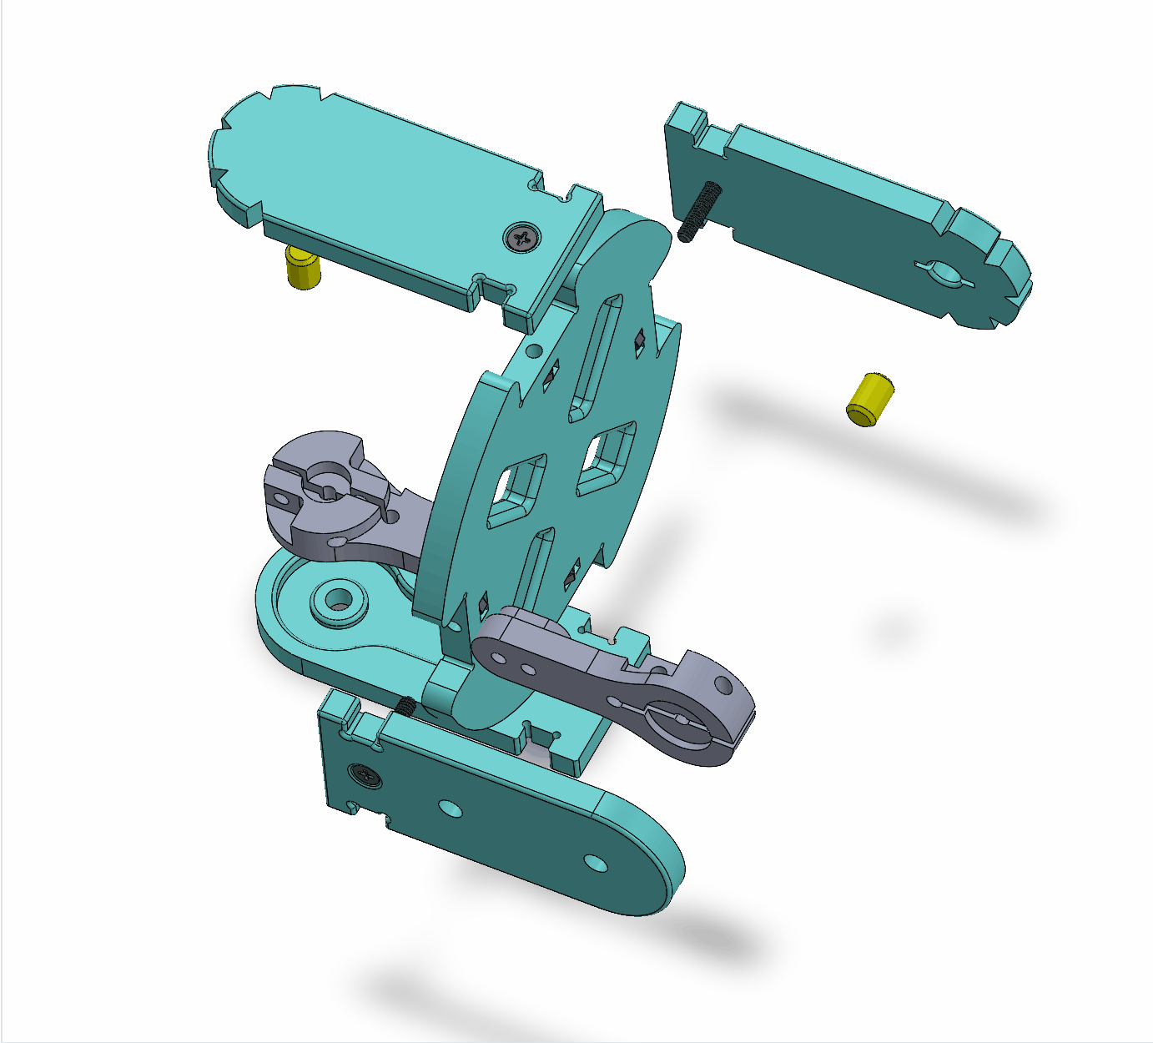
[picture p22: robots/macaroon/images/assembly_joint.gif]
joint_assembly


| Filename | Thumbnail | Required # |
| --- | --- | --- |
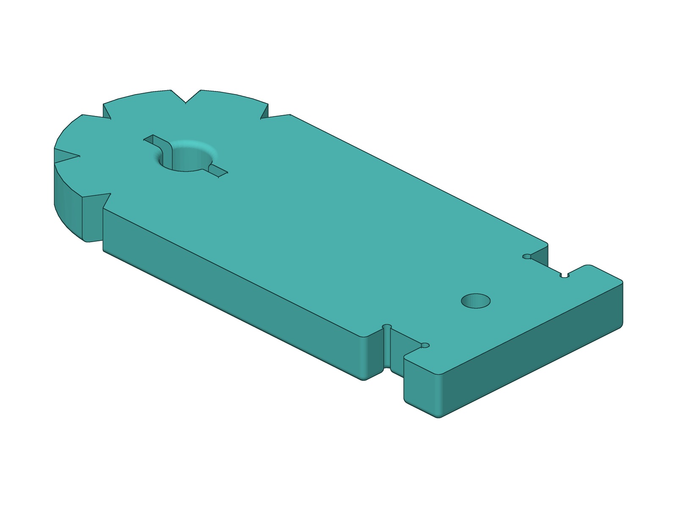
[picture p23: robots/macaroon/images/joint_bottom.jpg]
joint_bottom
| joint_bottom |  | 12 |
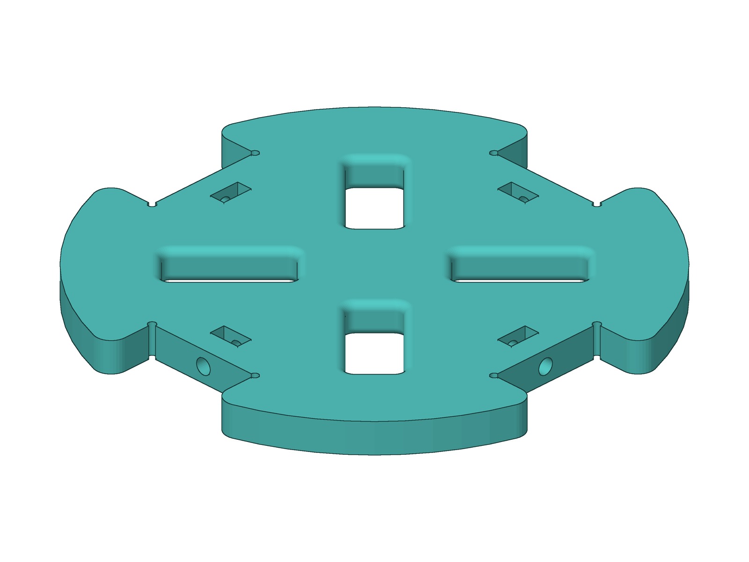
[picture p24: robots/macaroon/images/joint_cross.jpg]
joint_cross
| joint_cross  |  | 6 |
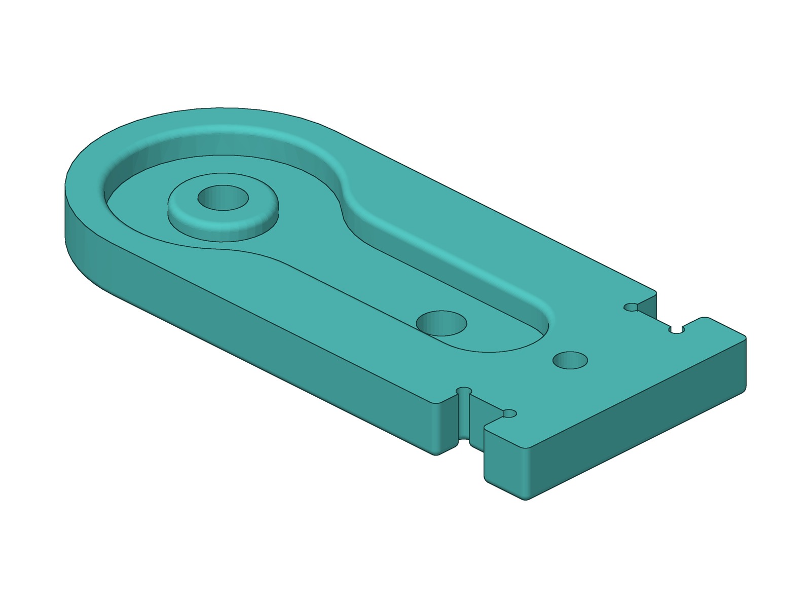
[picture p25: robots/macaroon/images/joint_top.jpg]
joint_top
| joint_top |  | 12 |

#### Step 1.3: Leg Components (x6)

**Assembly Notes:**

- Ensure bearings are properly seated
- Pins should slide in smoothly without forcing
- Check for smooth joint rotation before proceeding

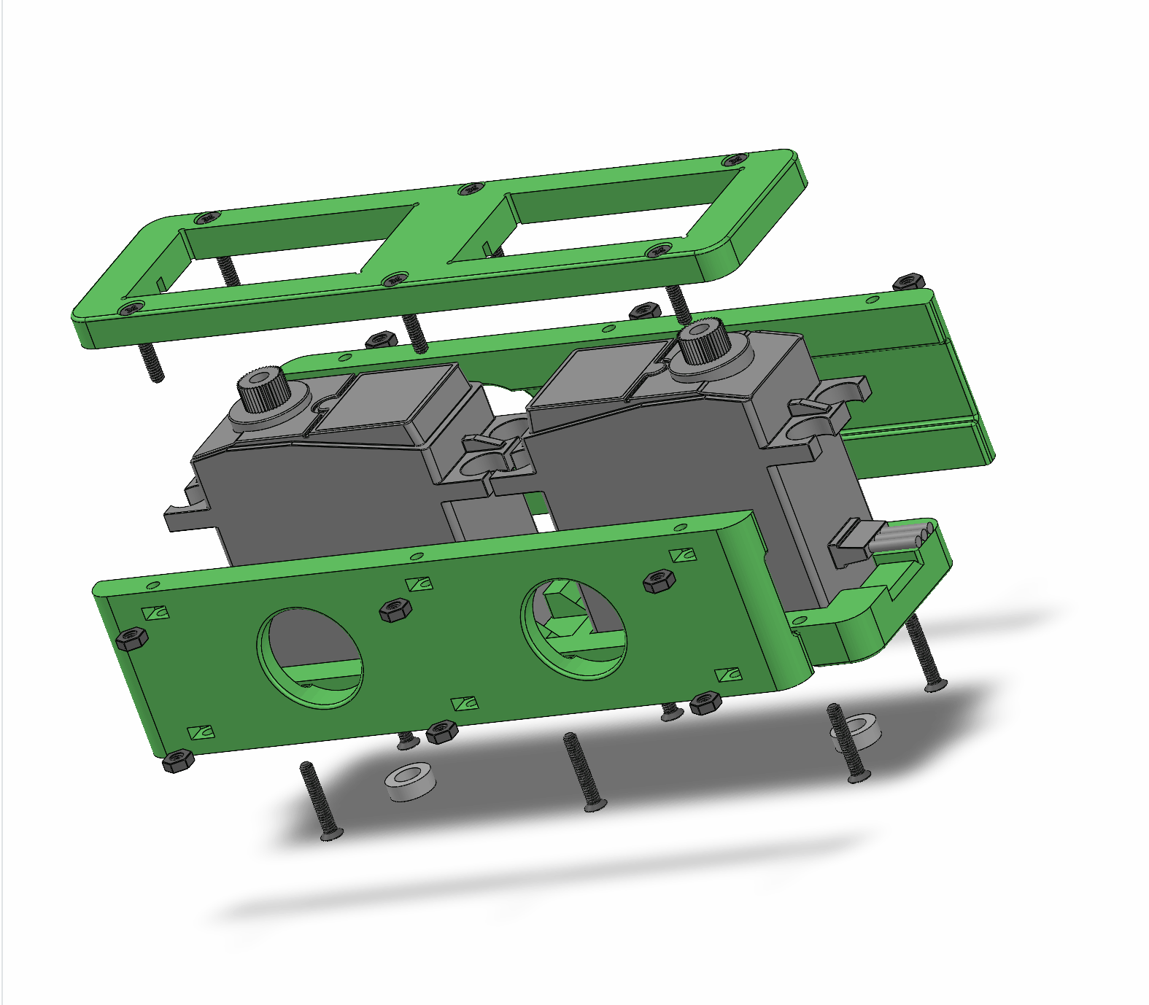
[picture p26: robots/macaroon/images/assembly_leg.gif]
leg_assembly


| Filename | Thumbnail | Required # |
| --- | --- | --- |
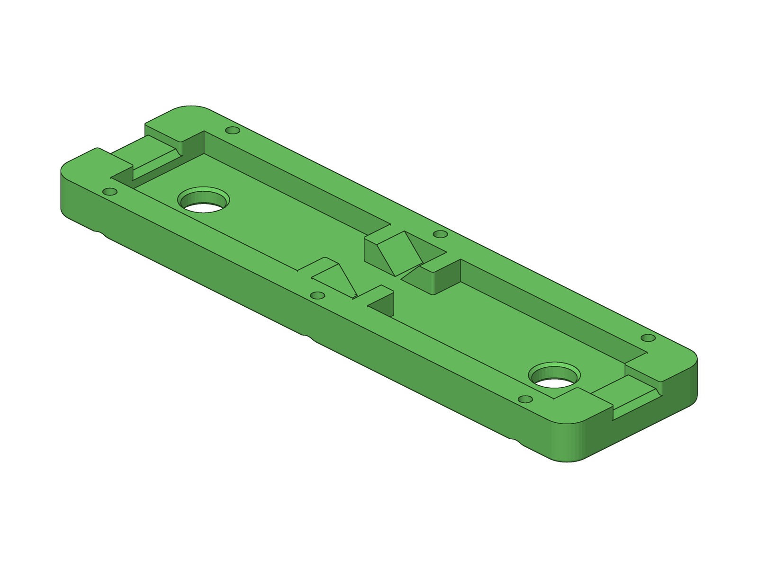
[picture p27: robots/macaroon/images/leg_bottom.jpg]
leg_bottom
| leg_bottom |  | 6 |
| leg_side | leg_side | 12 |
| leg_top | leg_top | 6 |

#### Step 1.4: Foot Components (x6 total: 3 standard + 3 mirrored)

**Important:** Match foot orientation with joint orientation!

- **Left side legs**: Use mirrored feet with mirrored joints
- **Right side legs**: Use standard feet with standard joints

_Refer to the fully assembled robot images for correct foot orientations_

foot_assembly

| Filename | Thumbnail | Required # | Note |
| --- | --- | --- | --- |
| foot_bottom | foot_bottom | 6 | |
| foot_top | foot_top | 6 | |
| foot_ground | foot_ground | 6 | |
| foot_tip | foot_tip | 6 | Recommend to print with TPU |

### Step 2: Hardware Components

**Pro Tip:** Organize all hardware into labeled containers before assembly to save time!

| Name | Spec | Required # | Usage |
| --- | --- | --- | --- |
| Screw | M2 × 6 mm hex socket | 36 | Servo mounting |
| Screw | M2 × 12 mm countersunk | 180 | General assembly |
| Nuts | M2 hex nut | 216 | Securing screws |
| Pin | M4 × 6 mm stainless steel (304) | 18 | Joint pivots |
| Bearing | MR74-2RS (4 mm ID × 7 mm OD × 2.5 mm width) | 18 | Smooth joint rotation |

**Where to Buy:** These are standard metric hardware available from Amazon, AliExpress, or local hardware stores.

## Software Setup

hexapod_model_label

### Prerequisites

- **Arduino IDE** (version 2.x recommended)
- **USB cable** compatible with your controller board
- **Required Libraries** (install via Arduino Library Manager):
  - `Adafruit_PWMServoDriver` (for PCA9685 control)
  - `AsyncUDP`, `ArduinoOTA`, `EEPROM` and `WebServer` (included with arduino-esp32)

### Step-by-Step Installation

1. **Install Arduino IDE** from [arduino.cc](https://www.arduino.cc/en/software)

2. **Add ESP32 Board Support**:
   - Follow the official [ESP32 Arduino installation guide](https://docs.espressif.com/projects/arduino-esp32/en/latest/installing.html)
   - Or add to Arduino IDE → File → Preferences → "Additional Board Manager URLs":

     ```
     https://raw.githubusercontent.com/espressif/arduino-esp32/gh-pages/package_esp32_index.json
     ```

   - Then install via Tools → Board → Boards Manager → Search "ESP32"

3. **Install Required Library**:
   - Go to Sketch → Include Library → Manage Libraries
   - Search for "Adafruit PWM Servo Driver"
   - Click Install

4. **Configure Board Settings**:
   - Board: "ESP32 Dev Module"
   - Upload Speed: "115200"
   - Flash Frequency: "80MHz"
   - Partition Scheme: "Default 4MB with spiffs"

5. **Open and Configure Code**:
   - Open [`./software/hexapod_esp32/hexapod_esp32.ino`](../../software/hexapod_esp32/hexapod_esp32.ino)
   - Select this robot in [`robot.h`](../../software/hexapod_esp32/robot.h): `#define ROBOT_MACAROON` must be the only uncommented `ROBOT_*` line. The same firmware drives every robot in the family; this picks Macaroon's motion tables and settings.

     ```cpp
     // #define ROBOT_NOUGAT
     // #define ROBOT_MOCHI
     #define ROBOT_MACAROON
     ```

   - WiFi (default: SSID="hexapod_macaroon", password="hexapod_1234"): the SSID is `APSSID` in [`src/robots/macaroon/robot_config.h`](../../software/hexapod_esp32/src/robots/macaroon/robot_config.h), the password is `APPSK` in [`config.h`](../../software/hexapod_esp32/config.h)

   - Configure servo pin mappings if using custom wiring:

     ```cpp
     static int left_legs[3][3] = { { 1, 2, 3 }, { 5, 6, 7 }, { 9, 8, 10 } };
     static int right_legs[3][3] = { { 10, 9, 8 }, { 13, 14, 15 }, { 7, 6, 5 } };
     ```

   - Calibration offsets are set through the web interface after assembly (see Calibration section)

6. **Upload Firmware**:
   - Connect ESP32 via USB
   - Select correct COM port in Tools → Port
   - Click Upload button
   - Open Serial Monitor (115200 baud) to see the WiFi AP IP address (default: 192.168.4.1)

### Repository Layout

Macaroon is one of several hexapods that share the same firmware and tools. Its hardware lives in this folder; the software is common to all of them.

```text
hexapod/
├── robots/
│   └── macaroon/           # This robot: README, 3d print/ (STL + Bambu Studio project), images/
├── images/                 # Images shared by all robots
└── software/
    ├── hexapod_esp32/      # ESP32 firmware (Arduino sketch), shared by all robots
    │   ├── robot.h         # Selects which robot the firmware is built for
    │   └── src/robots/macaroon/ # Macaroon's robot_config.h and generated motion.h
    └── path_tool/          # Gait generator that produces motion.h
        └── robots/macaroon.json # Macaroon's geometry and gait parameters
```

See the [ESP32 firmware README](../../software/hexapod_esp32/README.md) for the firmware's file structure.

#### Regenerating the Motion Tables

The gaits in `motion.h` are generated, not hand-written. Every table is derived from [`robots/macaroon.json`](../../software/path_tool/robots/macaroon.json), which holds the leg mount positions, link lengths, postures and gait parameters. To change one:

1. Install Python with `numpy`, then edit `robots/macaroon.json` (or add a generator in `path_tool.py`).
2. From [`software/path_tool`](../../software/path_tool/), run `python generate_motion.py macaroon`. It writes `software/hexapod_esp32/src/robots/macaroon/motion.h` directly. `lut_generator.ipynb` does the same interactively.
3. Re-upload the firmware.
4. A brand-new table also needs an entry in `motion_config[]` in `motion_control.ino`. See [Adding Custom Motions](../../software/hexapod_esp32/README.md#adding-custom-motions).

### Control Interface

#### Connection

The robot hosts its own Access Point — connect your phone or computer to it directly; it never joins your home router.

| Setting | Default | Where to change it |
| --- | --- | --- |
| WiFi SSID | `hexapod_macaroon` | `APSSID` in `src/robots/macaroon/robot_config.h` |
| WiFi password | `hexapod_1234` | `APPSK` in `config.h` |
| Robot IP | `192.168.4.1` | Fixed by the ESP32 AP |
| UDP port | `1234` | `UDP_PORT` in `config.h` |
| Web interface | `http://192.168.4.1` | — |

1. **Power on the hexapod** - connect the batteries and flip the toggle switch
2. **Join its WiFi network** - the robot runs its stand-up sequence as soon as a client connects
3. **Send commands** to `192.168.4.1:1234`, or open `http://192.168.4.1` for the calibration interface

#### Sending UDP Commands

The hexapod listens on UDP port `1234`. Three binary packet types share that port, and the **first byte selects the protocol** — the firmware dispatches on the magic number before it checks the length (the motion and session packets are both 6 bytes). All packets are little-endian and unpadded.

| Magic  | Packet | Size | Purpose |
| --- | --- | ---- | --- |
| `0xA5` | Motion command  | 6-7 B | Play one of the built-in gait look-up tables  |
| `0xA6` | Real-time pose  | 44 B | Stream raw servo positions for all 18 joints |
| `0xA7` | Session control | 6 B  | Enter/leave real-time mode, relax, keep-alive  |

##### Motion Commands (`0xA5`)

Byte 0 is the magic number, byte 1 the command ID, and bytes 2-5 a 32-bit sequence number. An optional byte 6 sets the gait speed in percent of the tuned speed (20-100; `0` leaves it unchanged). The ESP32 firmware starts at **60 %**, so clients sending only the 6-byte form walk at 60 % unless the speed is raised from the **Motion Speed** slider at `http://192.168.4.1`. See the [firmware README](../../software/hexapod_esp32/README.md#motion-speed) for details.

| ID  | Action | Legacy text command |
| --- | --- | --- |
| 0 | Stop and hold position  | `standby` |
| 1 | Walk forward | `walk0` |
| 2 | Walk backward | `walk180` |
| 3 | Walk right at 45° | `walkr45` |
| 4 | Walk right at 90° | `walkr90` |
| 5 | Walk right at 135° | `walkr135` |
| 6 | Walk left at 45° | `walkl45` |
| 7 | Walk left at 90° | `walkl90` |
| 8 | Walk left at 135° | `walkl135` |
| 9 | Fast walk forward | `fastforward` |
| 10  | Fast walk backward | `fastbackward` |
| 11  | Turn left in place | `turnleft` |
| 12  | Turn right in place | `turnright` |
| 13  | Climbing gait forward | `climbforward` |
| 14  | Climbing gait backward  | `climbbackward` |
| 15  | Body rotation — pitch | `rotatex` |
| 16  | Body rotation — roll | `rotatey` |
| 17  | Body rotation — yaw | `rotatez` |
| 18  | Body twist motion | `twist` |

**Example (Python):**

```python
import socket
import struct

# 0xA5 (magic), 1 (Walk forward), 0 (sequence number)
packet = struct.pack("<BBI", 0xA5, 1, 0)
sock = socket.socket(socket.AF_INET, socket.SOCK_DGRAM)
sock.sendto(packet, ("192.168.4.1", 1234))
```

##### Session Control (`0xA7`)

Same 6-byte layout as a motion command, with an action in byte 1:

| Action | Name  | Effect |
| --- | ----- | --- |
| 0 | Exit  | Leave real-time mode, resume LUT playback from standby |
| 1 | Enter | Enter real-time mode, holding the standby posture |
| 2 | Relax | Disable both PWM drivers so the servos go limp |
| 3 | Ping  | Keep-alive; resets the failsafe timer |

##### Real-Time Pose (`0xA6`)

A 44-byte packet carrying raw servo ticks for all 18 joints, which bypasses the motion look-up tables entirely. Receiving one implicitly enters real-time mode, and each joint then slews toward its target by at most `max_step` ticks per 20 ms cycle. If no packet arrives for 1 second the robot eases back to standby and returns to LUT control — send a ping while idle. Sending a motion command (`0xA5`) also leaves real-time mode, so the two control styles cannot fight over the servos.

See the [ESP32 UDP command reference](../../software/hexapod_esp32/README.md#udp-command-reference) for the full field layout, tick scale, and a streaming example.

**Legacy text commands:** the firmware still falls back to parsing plain command strings (the `Legacy text command` column above) when a packet matches none of the binary layouts, e.g. `sock.sendto(b":walk0:", ...)`. The `:` delimiters are optional — leading delimiters are skipped and the command ends at the first one. New clients should use the binary protocol.

**Boot Behavior:** The robot automatically performs a boot sequence (stands up) when a client connects to its WiFi network.

### Over-The-Air (OTA) Updates

The ESP32 supports wireless firmware updates:

1. **Power on** the robot and **connect** to its WiFi network
2. In Arduino IDE, go to **Tools → Port → Network Ports**
3. Select the hexapod from network ports
4. Click **Upload** as normal

**Important Note:** OTA is disabled once the robot enters real-time mode or receives a legacy text command — binary motion commands (`0xA5`) leave it enabled. Reboot the robot to re-enable OTA.

### Troubleshooting

**Upload fails:**

- Check USB cable (must support data transfer)
- Try different USB port
- Ensure correct board and port selected
- Hold BOOT button during upload

**Servos not responding:**

- Verify battery voltage (should be 7.4V nominal for 2S Li-ion setup)
- Check all servo connections match the wiring diagram
- Verify PCA9685 I2C addresses (default: 0x40 left, 0x41 right)
- Check enable pins (GPIO 19 for left, GPIO 26 for right)
- Test individual servos using `posture_calibration()` function
- Confirm servo pin mappings in `config.h` match your wiring

**WiFi connection issues:**

- Verify the SSID (`src/robots/macaroon/robot_config.h`) and password (`config.h`) (default: hexapod_macaroon/hexapod_1234)
- The hexapod creates an **Access Point** - connect to it, don't look for it on your router
- Ensure your device supports 2.4GHz WiFi (5GHz not supported)
- Default IP is always `192.168.4.1` when connected to the hexapod's AP

**OTA not working:**

- OTA is turned off by real-time mode and by legacy text commands - reboot to re-enable
- Ensure you're connected to the hexapod's WiFi network
- Check firewall settings on your computer

### Android App

Control your hexapod directly from your Android smartphone:

<a href="https://play.google.com/store/apps/details?id=com.rookiedev.hexapod">
  
</a>

The app provides an intuitive interface to:

- Connect to your hexapod's WiFi network
- Control movement with on-screen buttons
- Execute all available motion commands
- Monitor connection status

**Requirements:** Android device with WiFi capability

### Desktop Control Software

The [Hexapod Link](https://github.com/rookidroid/hexapod-link) can drive the robot live through the real-time pose streaming protocol.

## Calibration Guide

Proper calibration is **critical** for smooth walking. Take your time with this step!

### Understanding Servo Positions

All servos should be at 90° (neutral position) when the legs are in the reference positions shown below.

### Calibration Procedure

The firmware includes a **web-based calibration interface** that makes the calibration process much easier - no need to repeatedly edit code and re-upload firmware!

#### Step 1: Access the Calibration Interface

1. **Upload Firmware**: Flash the code to your controller with default offset values
2. **Power On**: Connect batteries and turn on the hexapod
3. **Connect to WiFi**: Join the hexapod's WiFi network (default SSID: `hexapod_macaroon`)
4. **Open Browser**: Navigate to `http://192.168.4.1`

Calibration Web Interface

#### Step 2: Enter Calibration Mode

1. Click the **"Enter Calibration Mode"** button
   - The hexapod will stop motion execution
   - All current offset values will be loaded
   - A grid showing all 6 legs (18 servos) will appear

2. **Check Leg Positions**: Compare each leg with the reference images below
   - **Coxa (hip) joint**: Should be perpendicular to body
   - **Femur (thigh) joint**: Should be horizontal
   - **Tibia (shin) joint**: Should form 90° angle with femur

#### Step 3: Adjust Offsets

For each misaligned servo:

1. **Locate the servo** in the web interface:
   - Left column: Left Leg 1, 2, 3
   - Right column: Right Leg 1, 2, 3
   - Each leg has 3 joints: Joint 1 (coxa), Joint 2 (femur), Joint 3 (tibia)

2. **Adjust the offset value**:
   - Use **+** and **-** buttons for fine adjustment (±1 tick per click)
   - Or type a value directly in the input field
   - Changes apply immediately to the servo
   - 1 tick ≈ 0.44° for most servos

3. **Observe the movement** and continue adjusting until the servo reaches the correct position

#### Step 4: Save Your Calibration

1. Once all servos are properly aligned, click **"Save Offsets"**
   - Offset values are saved to **EEPROM** (persistent storage)
   - Values are also printed to Serial Monitor as backup
   - The hexapod will remember these values even after power cycles

2. **Now tighten the servo horn screws** - With each servo in its correct neutral position, firmly tighten the small screws on each servo horn to secure them in place

3. Click **"Exit Calibration Mode"** to resume normal operation

#### Step 5: Test Walking

Send a walking command to verify smooth motion. If adjustments are needed, simply re-enter calibration mode and fine-tune.

### Reference Images

**Front View**

calibration_1

**Top View**

calibration_2

### Calibration Tips

- **Use the web interface**: Much faster than editing code and re-uploading
- **Start with one leg**: Calibrate completely before moving to the next
- **Make small adjustments**: Use the +/- buttons for precise control (±1 tick per click)
- **Real-time feedback**: Servos respond immediately as you adjust values
- **Save your work**: Don't forget to click "Save Offsets" when done!
- **Check screw tightness**: Loose servo horns will affect calibration
- **Servo horn position**: If offsets exceed ±25 ticks, consider repositioning the servo horn physically

## Related Projects

| Project | What it is |
| --- | --- |
| [Hexapod Link](https://github.com/rookidroid/hexapod-link) | Desktop application that drives the robot live over the real-time pose protocol |
| [Hexapod Android app](https://play.google.com/store/apps/details?id=com.rookiedev.hexapod) | Phone controller for the built-in gaits |
| [Hexapod Controller Board (Macaroon)](https://rookidroid.com/product/hexapod-controller-board-macaroon-esp32/) | The ESP32 controller board this build is designed around |
| [ESP32 firmware README](../../software/hexapod_esp32/README.md) | Firmware internals and the full UDP protocol reference |

## Contributing

Issues and pull requests are welcome — bug reports, print-setting tweaks, new gaits and documentation fixes all help. A few things that make a pull request easy to merge:

- Say which hardware you tested on (servo model, board revision, firmware branch).
- Match the existing style of the Arduino sketch tabs in `software/hexapod_esp32/`.
- Regenerate `motion.h` with the path tool instead of hand-editing the look-up tables.

## License

This project is licensed under the **GNU General Public License v3.0** — see [LICENSE](../../LICENSE) for the full text.

Copyright (C) 2024 - PRESENT rookidroid.com

## Support

- Website: [rookidroid.com](https://rookidroid.com/)
- Email: [info@rookidroid.com](mailto:info@rookidroid.com)
- Bugs and build questions: [GitHub Issues](https://github.com/rookidroid/hexapod/issues)

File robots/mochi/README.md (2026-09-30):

#  Hexapod Mochi

An 18-DOF, 3D-printed hexapod robot that runs on either an ESP32 or a Raspberry Pi Pico W — walk it from your phone over WiFi, or stream poses to it live from a computer.





hexapod_photohexapod_photo

**Jump to:** [Bill of Materials](#bill-of-materials-bom) · [Assembly](#assembly-instructions) · [Software Setup](#software-setup) · [Control Interface](#control-interface) · [Calibration](#calibration-guide) · [Troubleshooting](#troubleshooting)

<details>
<summary><b>Table of Contents</b></summary>

- [Introduction](#introduction)
  - [Specifications](#specifications)
  - [What You'll Build](#what-youll-build)
  - [Skill Level](#skill-level)
- [Bill of Materials (BOM)](#bill-of-materials-bom)
  - [Electronics Components](#electronics-components)
  - [Connection Diagram](#connection-diagram)
- [Assembly Instructions](#assembly-instructions)
  - [Overview](#overview)
  - [Safety Notes](#safety-notes)
  - [Step 1: 3D-Printed Parts](#step-1-3d-printed-parts)
  - [Step 2: Hardware Components](#step-2-hardware-components)
- [Software Setup](#software-setup)
  - [Prerequisites](#prerequisites)
  - [Step-by-Step Installation](#step-by-step-installation)
  - [Repository Layout](#repository-layout)
  - [Project File Structure](#project-file-structure)
  - [Control Interface](#control-interface)
  - [Over-The-Air (OTA) Updates](#over-the-air-ota-updates)
  - [Troubleshooting](#troubleshooting)
  - [Android App](#android-app)
  - [Desktop Control Software](#desktop-control-software)
- [Calibration Guide](#calibration-guide)
  - [Understanding Servo Positions](#understanding-servo-positions)
  - [Calibration Procedure](#calibration-procedure)
  - [Reference Images](#reference-images)
  - [Calibration Tips](#calibration-tips)
- [Related Projects](#related-projects)
- [Contributing](#contributing)
- [License](#license)
- [Support](#support)

</details>

## Introduction

This agile, 3D-printed hexapod robot is designed to work with either a Raspberry Pi PICO or an ESP32, providing flexibility and enhanced performance. Equipped with stronger and faster MG92B servos, it offers a range of advanced features, including:

- **Robust, durable structure**: 3D-printed parts designed for strength and easy assembly
- **WiFi-enabled remote control**: Control your hexapod wirelessly from your smartphone or computer
- **Smooth, agile movement**: Advanced motion algorithms for natural walking patterns
- **Web-based calibration interface**: Easy servo calibration through your browser with real-time adjustment (ESP32)
- **Real-time pose streaming**: Drive all 18 servos live from a computer over UDP (ESP32)
- **Over-the-air (OTA) firmware updates**: Update firmware without cables for easy maintenance

### Specifications

| Item | Value |
| ---- | ----- |
| **Degrees of freedom** | 18 (6 legs × 3 joints: coxa, femur, tibia) |
| **Actuators** | 18 × MG92B micro servos, 180° travel |
| **Controller** | ESP32 with dual PCA9685 PWM drivers (I²C `0x40` / `0x41`), or Raspberry Pi Pico W/2W driving the servos through PicoPWM |
| **Power** | 2 × 18650 Li-ion in series (2S) — 7.4 V nominal, 8.4 V fully charged |
| **Connectivity** | 2.4 GHz WiFi Access Point (the robot hosts its own network) |
| **Control** | UDP on `192.168.4.1:1234` — binary protocol on the ESP32, text commands on both boards |
| **Web interface** | Servo calibration at `http://192.168.4.1` (ESP32 firmware) |
| **Real-time streaming** | All 18 joints at 50 Hz, with per-joint slew limiting and a 1 s failsafe (ESP32 firmware) |
| **Firmware updates** | USB or over-the-air (OTA) over WiFi |
| **Resolution** | ~0.44° per servo tick (410 ticks over 180°) |

### What You'll Build

This project will guide you through building a fully functional hexapod robot with 18 degrees of freedom (3 joints per leg × 6 legs). The complete build typically takes 8-12 hours, including 3D printing, assembly, and calibration.

### Skill Level

- **Beginner-Intermediate**: Mechanical assembly skills required. No soldering is needed with a pre-assembled Controller Board ([ESP32](https://rookidroid.com/product/hexapod-controller-board-esp32/) or [Pico](https://rookidroid.com/product/hexapod-controller-board-pico/)) — the servos, switch and battery leads plug straight in.
- **Tools needed**: Hex key set and a small screwdriver
- **Only if you build your own wiring harness**: soldering iron, wire cutters/strippers

## Bill of Materials (BOM)

### Electronics Components

| Name | Thumbnail | Required # | Specifications | Note |
| --- | --- | --- | --- | --- |
| Controller Board | controller_board  | 1 | ESP32 | Purchase [Controller Board](https://rookidroid.com/product/hexapod-controller-board-mochi-esp32/). |
| MG92B Servo | mg92b | 18 | 180° rotation | Ensure all servos are from the same batch for consistency |
| Toggle Switch | switch | 1 | SPST, 12mm diameter | Purchase together with the [Controller Board](https://rookidroid.com/product/hexapod-controller-board-mochi-esp32/). |
| 18650 Battery | battery | 2 | 3.7V Li-ion, 2000mAh+ recommended | **Use protected batteries for safety** |
| 18650 Battery Holder | battery_holder | 1 | 2-cell holder with wire leads | A 3D-printable holder is available [here](https://rookidroid.com/product/18650-battery-holder/), or purchase together with the [Controller Board](https://rookidroid.com/product/hexapod-controller-board-mochi-esp32/). |

### Connection Diagram

diagram_esp32

## Assembly Instructions

### Overview

Follow these steps in order for the best results:

1. **3D Print all parts** (see parts list below)
2. **Prepare hardware** (organize screws, nuts, bearings, and pins)
3. **Assemble body** (install servos and controller)
4. **Build legs** (joint → leg → foot for each leg)
5. **Attach legs to body**
6. **Wire and test** (connect servos, upload firmware, calibrate)

**⚠️ Important:** Do NOT tighten the servo horn screws during assembly! Leave them loose to allow for rotation. You'll tighten them properly during the calibration process after adjusting each servo to its correct neutral position.

whole_assembly

### Safety Notes

- **Check battery polarity twice** before the first power-up — reversed polarity will destroy the controller board.
- **Keep fingers clear of the joints when powered.** Eighteen servos have enough torque between them to pinch hard.
- **Support the robot on the first power-on.** It runs its stand-up sequence automatically as soon as a client joins its WiFi network, so hold it or stand it on a box with the legs free.
- **Treat the Li-ion pack with respect**: protected cells only, a proper 2S charger, and never charge unattended.
- If a leg moves somewhere unexpected, **cut power with the toggle switch** rather than trying to hold the leg back.

### Step 1: 3D-Printed Parts

All STL files are located in the [`3d print`](./3d%20print/) folder, along with a ready-to-print Bambu Studio project (`hexapod_mochi.3mf`).

**Print Settings Recommendations:**

- Layer height: 0.2 mm
- Infill: 20-30%
- Material: PLA or PETG for the structure, TPU for the foot tips
- Supports: Required for some parts (check STL orientation)
- Print one leg's worth of parts first and test-fit it before committing to all six

#### Step 1.1: Body Components (x1 complete body)

**Assembly Tips:**

- Install servos before closing the body
- Route wires neatly to avoid pinching
- Test fit all parts before final assembly

body_assembly

| Filename | Thumbnail | Required # |
| --- | --- | --- |
| body_base | body_base | 1 |
| body_side | body_side | 6 |
| body_top | body_top | 1 |
| body_head | body_head | 1 |
| body_battery_top | body_battery_top | 1 |
| body_servo_side | body_servo_side | 12 |

#### Step 1.2: Joint Components (x6 total: 3 standard + 3 mirrored)

**Important:** Pay attention to joint orientation! Three legs use standard joints, three use mirrored joints.

- **Left side legs**: Use mirrored joints
- **Right side legs**: Use standard joints

_Refer to the fully assembled robot images for correct joint orientations_

joint_assembly

| Filename | Thumbnail | Required # |
| --- | --- | --- |
| joint_bottom | joint_bottom | 12 |
| joint_cross  | joint_cross | 6 |
| joint_top | joint_top | 12 |

#### Step 1.3: Leg Components (x6)

**Assembly Notes:**

- Ensure bearings are properly seated
- Pins should slide in smoothly without forcing
- Check for smooth joint rotation before proceeding

leg_assembly

| Filename | Thumbnail | Required # |
| --- | --- | --- |
| leg_bottom | leg_bottom | 6 |
| leg_side | leg_side | 12 |
| leg_top | leg_top | 6 |

#### Step 1.4: Foot Components (x6 total: 3 standard + 3 mirrored)

**Important:** Match foot orientation with joint orientation!

- **Left side legs**: Use mirrored feet with mirrored joints
- **Right side legs**: Use standard feet with standard joints

_Refer to the fully assembled robot images for correct foot orientations_

foot_assembly

| Filename | Thumbnail | Required # | Note |
| --- | --- | --- | --- |
| foot_bottom | foot_bottom | 6 | |
| foot_top | foot_top | 6 | |
| foot_ground | foot_ground | 6 | |
| foot_tip | foot_tip | 6 | Recommend to print with TPU |

### Step 2: Hardware Components

**Pro Tip:** Organize all hardware into labeled containers before assembly to save time!

| Name | Spec | Required # | Usage |
| --- | --- | --- | --- |
| Screw | M2 × 6 mm hex socket | 36 | Servo mounting |
| Screw | M2 × 12 mm countersunk | 180 | General assembly |
| Nuts | M2 hex nut | 216 | Securing screws |
| Pin | M4 × 6 mm stainless steel (304) | 18 | Joint pivots |
| Bearing | MR74-2RS (4 mm ID × 7 mm OD × 2.5 mm width) | 18 | Smooth joint rotation |

**Where to Buy:** These are standard metric hardware available from Amazon, AliExpress, or local hardware stores.

## Software Setup

hexapod_model_label

### Prerequisites

- **Arduino IDE** (version 2.x recommended)
- **USB cable** compatible with your controller board
- **Required Libraries** (install via Arduino Library Manager):
  - ESP32: `Adafruit_PWMServoDriver` (for PCA9685 control)
  - ESP32: `AsyncUDP` and `ArduinoOTA` (included with arduino-esp32)
  - Pico: No additional libraries needed (uses custom PicoPWM)

### Step-by-Step Installation

#### Option 1: ESP32 Setup

1. **Install Arduino IDE** from [arduino.cc](https://www.arduino.cc/en/software)

2. **Add ESP32 Board Support**:
   - Follow the official [ESP32 Arduino installation guide](https://docs.espressif.com/projects/arduino-esp32/en/latest/installing.html)
   - Or add to Arduino IDE → File → Preferences → "Additional Board Manager URLs":

     ```
     https://raw.githubusercontent.com/espressif/arduino-esp32/gh-pages/package_esp32_index.json
     ```

   - Then install via Tools → Board → Boards Manager → Search "ESP32"

3. **Install Required Library**:
   - Go to Sketch → Include Library → Manage Libraries
   - Search for "Adafruit PWM Servo Driver"
   - Click Install

4. **Configure Board Settings**:
   - Board: "ESP32 Dev Module"
   - Upload Speed: "115200"
   - Flash Frequency: "80MHz"
   - Partition Scheme: "Default 4MB with spiffs"

5. **Open and Configure Code**:
   - Open [`hexapod_esp32.ino`](../../software/hexapod_esp32/hexapod_esp32.ino)
   - Select this robot in [`robot.h`](../../software/hexapod_esp32/robot.h): `#define ROBOT_MOCHI` must be the only uncommented `ROBOT_*` line. The same firmware drives every robot in the family; this picks Mochi's motion tables and settings.

     ```cpp
     // #define ROBOT_NOUGAT
     #define ROBOT_MOCHI
     // #define ROBOT_MACAROON
     ```

   - WiFi (default: SSID="hexapod", password="hexapod_1234"): the SSID is `APSSID` in [`src/robots/mochi/robot_config.h`](../../software/hexapod_esp32/src/robots/mochi/robot_config.h), the password is `APPSK` in [`config.h`](../../software/hexapod_esp32/config.h)

   - Configure servo pin mappings if using custom wiring:

     ```cpp
     static int left_legs[3][3] = {{1, 2, 3}, {5, 6, 7}, {9, 8, 10}};
     static int right_legs[3][3] = {{10, 9, 8}, {13, 14, 15}, {7, 6, 5}};
     ```

   - Adjust calibration offset values after assembly (see Calibration section)

6. **Upload Firmware**:
   - Connect ESP32 via USB
   - Select correct COM port in Tools → Port
   - Click Upload button
   - Open Serial Monitor (115200 baud) to see the WiFi AP IP address (default: 192.168.4.1)

#### Option 2: Raspberry Pi Pico Setup (legacy)

> **Note:** The Pico firmware is no longer maintained. It predates the web calibration and real-time streaming features, and its `motion.h` was generated for Nougat's geometry. The ESP32 firmware is recommended.

1. **Install Arduino IDE and Arduino-Pico Core**:
   - Install [Arduino IDE](https://www.arduino.cc/en/software)
   - Follow [arduino-pico installation guide](https://github.com/earlephilhower/arduino-pico)
   - Add board manager URL: `https://github.com/earlephilhower/arduino-pico/releases/download/global/package_rp2040_index.json`

2. **Configure Board Settings**:
   - Board: "Raspberry Pi Pico W" (or "Raspberry Pi Pico 2W")
   - **Flash Size: Must select option with "FS: 1MB"** (e.g., "2MB (Sketch: 1MB, FS: 1MB)")
   - Upload Method: "Default (UF2)"

3. **Open and Configure Code**:
   - Open [`hexapod_pico.ino`](../../software/hexapod_pico/hexapod_pico.ino)
   - Edit `config.h` for WiFi credentials (default: SSID="hexapod", password="hexapod_1234")
   - Configure servo pin mappings and calibration offsets as needed

4. **Upload Firmware**:
   - Hold BOOTSEL button while connecting Pico via USB
   - Release button when Pico appears as mass storage device
   - Select the Pico board and upload through Arduino IDE
   - Robot will perform boot-up sequence after upload

### Repository Layout

Mochi is one of several hexapods that share the same firmware and tools. Its hardware lives in this folder; the software is common to all of them.

```text
hexapod/
├── robots/
│   └── mochi/              # This robot: README, 3d print/ (STL + Bambu Studio project), images/
├── images/                 # Images shared by all robots
└── software/
    ├── hexapod_esp32/      # ESP32 firmware (Arduino sketch), shared by all robots
    │   ├── robot.h         # Selects which robot the firmware is built for
    │   └── src/robots/mochi/ # Mochi's robot_config.h and generated motion.h
    ├── hexapod_pico/       # Legacy Raspberry Pi Pico firmware
    └── path_tool/          # Gait generator that produces motion.h
        └── robots/mochi.json # Mochi's geometry and gait parameters
```

See the [ESP32 firmware README](../../software/hexapod_esp32/README.md) for the firmware's file structure.

#### Regenerating the Motion Tables

The gaits in `motion.h` are generated, not hand-written. Every table is derived from [`robots/mochi.json`](../../software/path_tool/robots/mochi.json), which holds the leg mount positions, link lengths, postures and gait parameters. To change one:

1. Install Python with `numpy`, then edit `robots/mochi.json` (or add a generator in `path_tool.py`).
2. From [`software/path_tool`](../../software/path_tool/), run `python generate_motion.py mochi`. It writes `software/hexapod_esp32/src/robots/mochi/motion.h` directly. `lut_generator.ipynb` does the same interactively.
3. Re-upload the firmware.
4. A brand-new table also needs an entry in `motion_config[]` in `motion_control.ino`. See [Adding Custom Motions](../../software/hexapod_esp32/README.md#adding-custom-motions).

### Control Interface

#### Connection

The robot hosts its own Access Point — connect your phone or computer to it directly; it never joins your home router.

| Setting | Default | Where to change it |
| --- | --- | --- |
| WiFi SSID | `hexapod` | `APSSID` in `src/robots/mochi/robot_config.h` |
| WiFi password | `hexapod_1234` | `APPSK` in `config.h` |
| Robot IP | `192.168.4.1` | Fixed by the board's AP (ESP32 and Pico alike) |
| UDP port | `1234` | `UDP_PORT` in `config.h` |
| Web interface | `http://192.168.4.1` | ESP32 firmware only |

1. **Power on the hexapod** - connect the batteries and flip the toggle switch
2. **Join its WiFi network** - the robot runs its stand-up sequence as soon as a client connects
3. **Send commands** to `192.168.4.1:1234`, or open `http://192.168.4.1` for the calibration interface

#### Sending UDP Commands

The hexapod listens on UDP port `1234`. The ESP32 firmware speaks a binary protocol in which the **first byte selects the packet type**; the Pico firmware and older clients use the plain-text commands below.

| Magic  | Packet | Size | Purpose |
| --- | --- | ---- | --- |
| `0xA5` | Motion command  | 6-7 B | Play one of the built-in gait look-up tables |
| `0xA6` | Real-time pose  | 44 B | Stream raw servo positions for all 18 joints |
| `0xA7` | Session control | 6 B  | Enter/leave real-time mode, relax, keep-alive |

A motion command is the magic byte, a command ID, and a 32-bit sequence number — little-endian and unpadded:

```python
import socket
import struct

# 0xA5 (magic), 1 (Walk forward), 0 (sequence number)
packet = struct.pack("<BBI", 0xA5, 1, 0)
sock = socket.socket(socket.AF_INET, socket.SOCK_DGRAM)
sock.sendto(packet, ("192.168.4.1", 1234))
```

Append an optional seventh byte to set the gait speed, in percent of the tuned speed (20-100; `0` leaves it unchanged). The ESP32 firmware starts at **60 %**, so clients sending only the 6-byte form walk at 60 % unless the speed is raised from the **Motion Speed** slider at `http://192.168.4.1`. See the [firmware README](../../software/hexapod_esp32/README.md#motion-speed) for details.

| ID  | Action | Text command |
| --- | --- | --- |
| 0 | Stop and hold position  | `standby` |
| 1 | Walk forward | `walk0` |
| 2 | Walk backward | `walk180` |
| 3 | Walk right at 45° | `walkr45` |
| 4 | Walk right at 90° | `walkr90` |
| 5 | Walk right at 135° | `walkr135` |
| 6 | Walk left at 45° | `walkl45` |
| 7 | Walk left at 90° | `walkl90` |
| 8 | Walk left at 135° | `walkl135` |
| 9 | Fast walk forward | `fastforward` |
| 10  | Fast walk backward | `fastbackward`  |
| 11  | Turn left in place | `turnleft` |
| 12  | Turn right in place | `turnright` |
| 13  | Climbing gait forward | `climbforward`  |
| 14  | Climbing gait backward  | `climbbackward` |
| 15  | Body rotation — pitch | `rotatex` |
| 16  | Body rotation — roll | `rotatey` |
| 17  | Body rotation — yaw | `rotatez` |
| 18  | Body twist motion | `twist` |

The real-time pose (`0xA6`) and session control (`0xA7`) packets, their field layouts and the failsafe behaviour are documented in the [ESP32 UDP command reference](../../software/hexapod_esp32/README.md#udp-command-reference).

**Text commands:** both firmwares accept plain command strings (the `Text command` column above), e.g. `sock.sendto(b":walk0:", ("192.168.4.1", 1234))`. The `:` delimiters are optional — leading delimiters are skipped and the command ends at the first one. This is the only interface on the Pico; new ESP32 clients should use the binary protocol.

**Boot Behavior:** The robot automatically performs a boot sequence (stands up) when a client connects to its WiFi network.

### Over-The-Air (OTA) Updates

Both ESP32 and Pico support wireless firmware updates:

1. **Power on** the robot and **connect** to its WiFi network
2. In Arduino IDE, go to **Tools → Port → Network Ports**
3. Select the hexapod from network ports
4. Click **Upload** as normal

**Important Notes:**

- For ESP32: OTA survives binary motion commands (`0xA5`), but is switched off once the robot enters real-time mode or receives a text command. Reboot to re-enable it.
- For Pico: Ensure Flash Size includes "FS: 1MB" in board settings for OTA to work.

### Troubleshooting

**Upload fails:**

- Check USB cable (must support data transfer)
- Try different USB port
- Ensure correct board and port selected
- For ESP32: Hold BOOT button during upload

**Servos not responding:**

- Verify battery voltage (should be 7.4V nominal for 2S Li-ion setup)
- Check all servo connections match the wiring diagram
- For ESP32: Verify PCA9685 I2C addresses (default: 0x40 left, 0x41 right)
- For ESP32: Check enable pins (GPIO 19 for left, GPIO 26 for right)
- Test individual servos using `posture_calibration()` function
- Confirm servo pin mappings in `config.h` match your wiring

**WiFi connection issues:**

- Verify the SSID (`src/robots/mochi/robot_config.h`) and password (`config.h`) (default: hexapod/hexapod_1234)
- The hexapod creates an **Access Point** - connect to it, don't look for it on your router
- Ensure your device supports 2.4GHz WiFi (5GHz not supported)
- Default IP is always `192.168.4.1` when connected to the hexapod's AP

**OTA not working:**

- For ESP32: real-time mode and text commands turn OTA off - reboot to re-enable
- Ensure you're connected to the hexapod's WiFi network
- Check firewall settings on your computer
- For Pico: Verify Flash Size setting includes "FS: 1MB"

### Android App

Control your hexapod directly from your Android smartphone:

<a href="https://play.google.com/store/apps/details?id=com.rookiedev.hexapod">
  
</a>

The app provides an intuitive interface to:

- Connect to your hexapod's WiFi network
- Control movement with on-screen buttons
- Execute all available motion commands
- Monitor connection status

**Requirements:** Android device with WiFi capability

### Desktop Control Software

[Hexapod Link](https://github.com/rookidroid/hexapod-link) drives the robot live through the real-time pose streaming protocol (ESP32 firmware).

## Calibration Guide

Proper calibration is **critical** for smooth walking. Take your time with this step!

### Understanding Servo Positions

All servos should be at 90° (neutral position) when the legs are in the reference positions shown below.

### Calibration Procedure

The hexapod now includes a **web-based calibration interface** that makes the calibration process much easier - no need to repeatedly edit code and re-upload firmware!

#### Step 1: Access the Calibration Interface

1. **Upload Firmware**: Flash the code to your controller with default offset values
2. **Power On**: Connect batteries and turn on the hexapod
3. **Connect to WiFi**: Join the hexapod's WiFi network (default SSID: `hexapod`)
4. **Open Browser**: Navigate to `http://192.168.4.1`

Calibration Web Interface

#### Step 2: Enter Calibration Mode

1. Click the **"Enter Calibration Mode"** button
   - The hexapod will stop motion execution
   - All current offset values will be loaded
   - A grid showing all 6 legs (18 servos) will appear

2. **Check Leg Positions**: Compare each leg with the reference images below
   - **Coxa (hip) joint**: Should be perpendicular to body
   - **Femur (thigh) joint**: Should be horizontal
   - **Tibia (shin) joint**: Should form 90° angle with femur

#### Step 3: Adjust Offsets

For each misaligned servo:

1. **Locate the servo** in the web interface:
   - Left column: Left Leg 1, 2, 3
   - Right column: Right Leg 1, 2, 3
   - Each leg has 3 joints: Joint 1 (coxa), Joint 2 (femur), Joint 3 (tibia)

2. **Adjust the offset value**:
   - Use **+** and **-** buttons for fine adjustment (±1 tick per click)
   - Or type a value directly in the input field
   - Changes apply immediately to the servo
   - 1 tick ≈ 0.44° for most servos

3. **Observe the movement** and continue adjusting until the servo reaches the correct position

#### Step 4: Save Your Calibration

1. Once all servos are properly aligned, click **"Save Offsets"**
   - Offset values are saved to **EEPROM** (persistent storage)
   - Values are also printed to Serial Monitor as backup
   - The hexapod will remember these values even after power cycles

2. **Now tighten the servo horn screws** - With each servo in its correct neutral position, firmly tighten the small screws on each servo horn to secure them in place

3. Click **"Exit Calibration Mode"** to resume normal operation

#### Step 5: Test Walking

Send a walking command to verify smooth motion. If adjustments are needed, simply re-enter calibration mode and fine-tune.

### Reference Images

**Front View**

calibration_1

**Top View**

calibration_2

### Calibration Tips

- **Use the web interface**: Much faster than editing code and re-uploading
- **Start with one leg**: Calibrate completely before moving to the next
- **Make small adjustments**: Use the +/- buttons for precise control (±1 tick per click)
- **Real-time feedback**: Servos respond immediately as you adjust values
- **Save your work**: Don't forget to click "Save Offsets" when done!
- **Check screw tightness**: Loose servo horns will affect calibration
- **Servo horn position**: If offsets exceed ±25 ticks, consider repositioning the servo horn physically

## Related Projects

| Project | What it is |
| --- | --- |
| [Hexapod Link](https://github.com/rookidroid/hexapod-link) | Desktop application that drives the robot live over the real-time pose protocol |
| [Hexapod Android app](https://play.google.com/store/apps/details?id=com.rookiedev.hexapod) | Phone controller for the built-in gaits |
| [Hexapod Controller Board](https://rookidroid.com/product/hexapod-controller-board-mochi-esp32/) | The ESP32 controller board this build is designed around |
| [ESP32 firmware README](../../software/hexapod_esp32/README.md) | Firmware internals and the full UDP protocol reference |

## Contributing

Issues and pull requests are welcome — bug reports, print-setting tweaks, new gaits and documentation fixes all help. A few things that make a pull request easy to merge:

- Say which hardware you tested on (controller board, servo model, firmware branch).
- Match the existing style of the Arduino sketch tabs in `software/hexapod_esp32/` and `software/hexapod_pico/`.
- Regenerate `motion.h` with the path tool instead of hand-editing the look-up tables.

## License

This project is licensed under the **GNU General Public License v3.0** — see [LICENSE](../../LICENSE) for the full text.

Copyright (C) 2024 - PRESENT rookidroid.com

## Support

- Website: [rookidroid.com](https://rookidroid.com/)
- Email: [info@rookidroid.com](mailto:info@rookidroid.com)
- Bugs and build questions: [GitHub Issues](https://github.com/rookidroid/hexapod/issues)

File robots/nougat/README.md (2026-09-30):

#  Hexapod Nougat

An 18-DOF, 3D-printed hexapod robot powered by an ESP32 — walk it from your phone over WiFi, or stream poses to it live from a computer.





hexapod_photo

**Jump to:** [Bill of Materials](#bill-of-materials-bom) · [Assembly](#assembly-instructions) · [Software Setup](#software-setup) · [Control Interface](#control-interface) · [Calibration](#calibration-guide) · [Troubleshooting](#troubleshooting)

<details>
<summary><b>Table of Contents</b></summary>

- [Introduction](#introduction)
  - [Specifications](#specifications)
  - [What You'll Build](#what-youll-build)
  - [Skill Level](#skill-level)
- [Bill of Materials (BOM)](#bill-of-materials-bom)
  - [Electronics Components](#electronics-components)
  - [Connection Diagram](#connection-diagram)
- [Assembly Instructions](#assembly-instructions)
  - [Overview](#overview)
  - [Safety Notes](#safety-notes)
  - [Step 1: 3D-Printed Parts](#step-1-3d-printed-parts)
  - [Step 2: Hardware Components](#step-2-hardware-components)
- [Software Setup](#software-setup)
  - [Prerequisites](#prerequisites)
  - [Step-by-Step Installation](#step-by-step-installation)
  - [Repository Layout](#repository-layout)
  - [Project File Structure](#project-file-structure)
  - [Control Interface](#control-interface)
  - [Over-The-Air (OTA) Updates](#over-the-air-ota-updates)
  - [Troubleshooting](#troubleshooting)
  - [Android App](#android-app)
  - [Desktop Control Software](#desktop-control-software)
- [Calibration Guide](#calibration-guide)
  - [Understanding Servo Positions](#understanding-servo-positions)
  - [Calibration Procedure](#calibration-procedure)
  - [Reference Images](#reference-images)
  - [Calibration Tips](#calibration-tips)
- [Related Projects](#related-projects)
- [Contributing](#contributing)
- [License](#license)
- [Support](#support)

</details>

## Introduction

This agile, 3D-printed hexapod robot is designed to work with either a Raspberry Pi PICO or an ESP32, providing flexibility and enhanced performance. Equipped with stronger and faster 21G servos, it offers a range of advanced features, including:

- **Robust, durable structure**: 3D-printed parts designed for strength and easy assembly
- **WiFi-enabled remote control**: Control your hexapod wirelessly from your smartphone or computer
- **Smooth, agile movement**: Advanced motion algorithms for natural walking patterns
- **Web-based calibration interface**: Easy servo calibration through your browser with real-time adjustment (ESP32)
- **Real-time pose streaming**: Drive all 18 servos live from a computer over UDP (ESP32)
- **Over-the-air (OTA) firmware updates**: Update firmware without cables for easy maintenance

### Specifications

| Item | Value |
| ---- | ----- |
| **Degrees of freedom** | 18 (6 legs × 3 joints: coxa, femur, tibia) |
| **Actuators** | 18 × 21G digital servos, 180° travel |
| **Controller** | ESP32 with dual PCA9685 PWM drivers (I²C `0x40` / `0x41`); Raspberry Pi Pico W/2W firmware is also included |
| **Power** | 2 × 18650 Li-ion in series (2S1P) — 7.4 V nominal, 8.4 V fully charged |
| **Connectivity** | 2.4 GHz WiFi Access Point (the robot hosts its own network) |
| **Control** | UDP on `192.168.4.1:1234` — binary protocol on the ESP32, text commands on both boards |
| **Web interface** | Servo calibration at `http://192.168.4.1` (ESP32 firmware) |
| **Real-time streaming** | All 18 joints at 50 Hz, with per-joint slew limiting and a 1 s failsafe (ESP32 firmware) |
| **Firmware updates** | USB or over-the-air (OTA) over WiFi |
| **Resolution** | ~0.44° per servo tick (410 ticks over 180°) |

### What You'll Build

This project will guide you through building a fully functional hexapod robot with 18 degrees of freedom (3 joints per leg × 6 legs). The complete build typically takes 8-12 hours, including 3D printing, assembly, and calibration.

### Skill Level

- **Beginner-Intermediate**: Mechanical assembly skills required. No soldering is needed with the pre-assembled [Controller Board](https://rookidroid.com/product/hexapod-controller-board-mochi-esp32/) — the servos, switch and battery leads plug straight in.
- **Tools needed**: Hex key set and a small screwdriver
- **Only if you build your own wiring harness**: soldering iron, wire cutters/strippers

## Bill of Materials (BOM)

### Electronics Components

| Name | Thumbnail | Required # | Specifications | Note |
| --- | --- | --- | --- | --- |
| Controller Board | controller_board  | 1 | ESP32 | Purchase [Controller Board](https://rookidroid.com/product/hexapod-controller-board-mochi-esp32/). |
| 21G Servo | 21g_servo | 18 | 180° rotation, digital | Ensure all servos are from the same batch for consistency |
| Toggle Switch | switch | 1 | SPST, 12mm diameter | Purchase together with the [Controller Board](https://rookidroid.com/product/hexapod-controller-board-mochi-esp32/). |
| 18650 Battery | battery | 2 | 3.7V Li-ion, 2000mAh+ recommended | **Use protected batteries for safety** |
| 18650 Battery Holder | battery_holder | 1 | 2-cell holder with wire leads | A 3D-printable holder is available [here](https://rookidroid.com/product/18650-battery-holder/), or purchase together with the [Controller Board](https://rookidroid.com/product/hexapod-controller-board-mochi-esp32/). |

### Connection Diagram

diagram_esp32

## Assembly Instructions

### Overview

Follow these steps in order for the best results:

1. **3D Print all parts** (see parts list below)
2. **Prepare hardware** (organize screws, nuts, bearings, and pins)
3. **Assemble body** (install servos and controller)
4. **Build legs** (joint → leg → foot for each leg)
5. **Attach legs to body**
6. **Wire and test** (connect servos, upload firmware, calibrate)

**⚠️ Important:** Do NOT tighten the servo horn screws during assembly! Leave them loose to allow for rotation. You'll tighten them properly during the calibration process after adjusting each servo to its correct neutral position.

whole_assembly

### Safety Notes

- **Check battery polarity twice** before the first power-up — reversed polarity will destroy the controller board.
- **Keep fingers clear of the joints when powered.** Eighteen servos have enough torque between them to pinch hard.
- **Support the robot on the first power-on.** It runs its stand-up sequence automatically as soon as a client joins its WiFi network, so hold it or stand it on a box with the legs free.
- **Treat the Li-ion pack with respect**: protected cells only, a proper 2S charger, and never charge unattended.
- If a leg moves somewhere unexpected, **cut power with the toggle switch** rather than trying to hold the leg back.

### Step 1: 3D-Printed Parts

All STL files are located in the [`3d print`](./3d%20print/) folder, along with a ready-to-print Bambu Studio project (`nougat.3mf`).

**Print Settings Recommendations:**

- Layer height: 0.2 mm
- Infill: 20-30%
- Material: PLA or PETG for the structure, TPU for the foot tips
- Supports: Required for some parts (check STL orientation)
- Print one leg's worth of parts first and test-fit it before committing to all six

#### Step 1.1: Body Components (x1 complete body)

**Assembly Tips:**

- Install servos before closing the body
- Route wires neatly to avoid pinching
- Test fit all parts before final assembly

body_assembly

| Filename | Thumbnail | Required # |
| --- | --- | --- |
| body_base | body_base | 1 |
| body_side | body_side | 6 |
| body_top | body_top | 1 |
| body_head | body_head | 1 |
| body_battery | body_battery | 1 |
| body_servo_side  | body_servo_side | 12 |

#### Step 1.2: Joint Components (x6 total: 3 standard + 3 mirrored)

**Important:** Pay attention to joint orientation! Three legs use standard joints, three use mirrored joints.

- **Left side legs**: Use mirrored joints
- **Right side legs**: Use standard joints

_Refer to the fully assembled robot images for correct joint orientations_

joint_assembly

| Filename | Thumbnail | Required # |
| --- | --- | --- |
| joint_bottom | joint_bottom | 12 |
| joint_cross  | joint_cross | 6 |
| joint_top | joint_top | 12 |

#### Step 1.3: Leg Components (x6)

**Assembly Notes:**

- Ensure bearings are properly seated
- Pins should slide in smoothly without forcing
- Check for smooth joint rotation before proceeding

leg_assembly

| Filename | Thumbnail | Required # |
| --- | --- | --- |
| leg_bottom | leg_bottom | 6 |
| leg_side | leg_side | 12 |
| leg_top | leg_top | 6 |

#### Step 1.4: Foot Components (x6 total: 3 standard + 3 mirrored)

**Important:** Match foot orientation with joint orientation!

- **Left side legs**: Use mirrored feet with mirrored joints
- **Right side legs**: Use standard feet with standard joints

_Refer to the fully assembled robot images for correct foot orientations_

foot_assembly

| Filename | Thumbnail | Required # | Note |
| --- | --- | --- | --- |
| foot_bottom | foot_bottom | 6 | |
| foot_top | foot_top | 6 | |
| foot_ground | foot_ground | 6 | |
| foot_tip | foot_tip | 6 | Recommend to print with TPU |

### Step 2: Hardware Components

**Pro Tip:** Organize all hardware into labeled containers before assembly to save time!

| Name | Spec | Required # | Usage |
| --- | --- | --- | --- |
| Screw | M2 × 6 mm hex socket | 36 | Servo mounting |
| Screw | M2 × 12 mm countersunk | 180 | General assembly |
| Nuts | M2 hex nut | 216 | Securing screws |
| Pin | M4 × 6 mm stainless steel (304) | 18 | Joint pivots |
| Bearing | MR74-2RS (4 mm ID × 7 mm OD × 2.5 mm width) | 18 | Smooth joint rotation |

**Where to Buy:** These are standard metric hardware available from Amazon, AliExpress, or local hardware stores.

## Software Setup

hexapod_model_label

### Prerequisites

- **Arduino IDE** (version 2.x recommended)
- **USB cable** compatible with your controller board
- **Required Libraries** (install via Arduino Library Manager):
  - ESP32: `Adafruit_PWMServoDriver` (for PCA9685 control)
  - ESP32: `AsyncUDP`, `ArduinoOTA`, `EEPROM` and `WebServer` (included with arduino-esp32)
  - Pico: No additional libraries needed (uses custom PicoPWM)

### Step-by-Step Installation

#### Option 1: ESP32 Setup

1. **Install Arduino IDE** from [arduino.cc](https://www.arduino.cc/en/software)

2. **Add ESP32 Board Support**:
   - Follow the official [ESP32 Arduino installation guide](https://docs.espressif.com/projects/arduino-esp32/en/latest/installing.html)
   - Or add to Arduino IDE → File → Preferences → "Additional Board Manager URLs":

     ```
     https://raw.githubusercontent.com/espressif/arduino-esp32/gh-pages/package_esp32_index.json
     ```

   - Then install via Tools → Board → Boards Manager → Search "ESP32"

3. **Install Required Library**:
   - Go to Sketch → Include Library → Manage Libraries
   - Search for "Adafruit PWM Servo Driver"
   - Click Install

4. **Configure Board Settings**:
   - Board: "ESP32 Dev Module"
   - Upload Speed: "115200"
   - Flash Frequency: "80MHz"
   - Partition Scheme: "Default 4MB with spiffs"

5. **Open and Configure Code**:
   - Open [`./software/hexapod_esp32/hexapod_esp32.ino`](../../software/hexapod_esp32/hexapod_esp32.ino)
   - Select this robot in [`robot.h`](../../software/hexapod_esp32/robot.h): `#define ROBOT_NOUGAT` must be the only uncommented `ROBOT_*` line. The same firmware drives every robot in the family; this picks Nougat's motion tables and settings.

     ```cpp
     #define ROBOT_NOUGAT
     // #define ROBOT_MOCHI
     // #define ROBOT_MACAROON
     ```

   - WiFi (default: SSID="hexapod_nougat", password="hexapod_1234"): the SSID is `APSSID` in [`src/robots/nougat/robot_config.h`](../../software/hexapod_esp32/src/robots/nougat/robot_config.h), the password is `APPSK` in [`config.h`](../../software/hexapod_esp32/config.h)

   - Configure servo pin mappings if using custom wiring:

     ```cpp
     static int left_legs[3][3] = { { 1, 2, 3 }, { 5, 6, 7 }, { 9, 8, 10 } };
     static int right_legs[3][3] = { { 10, 9, 8 }, { 13, 14, 15 }, { 7, 6, 5 } };
     ```

   - Calibration offsets are set through the web interface after assembly (see Calibration section)

6. **Upload Firmware**:
   - Connect ESP32 via USB
   - Select correct COM port in Tools → Port
   - Click Upload button
   - Open Serial Monitor (115200 baud) to see the WiFi AP IP address (default: 192.168.4.1)

#### Option 2: Raspberry Pi Pico Setup (legacy)

> **Note:** The Pico firmware is no longer maintained. It predates the web calibration and real-time streaming features, and its `motion.h` was generated for Nougat's geometry. The ESP32 firmware is recommended.

1. **Install Arduino IDE and Arduino-Pico Core**:
   - Install [Arduino IDE](https://www.arduino.cc/en/software)
   - Follow [arduino-pico installation guide](https://github.com/earlephilhower/arduino-pico)
   - Add board manager URL: `https://github.com/earlephilhower/arduino-pico/releases/download/global/package_rp2040_index.json`

2. **Configure Board Settings**:
   - Board: "Raspberry Pi Pico W" (or "Raspberry Pi Pico 2W")
   - **Flash Size: Must select option with "FS: 1MB"** (e.g., "2MB (Sketch: 1MB, FS: 1MB)")
   - Upload Method: "Default (UF2)"

3. **Open and Configure Code**:
   - Open [`./software/hexapod_pico/hexapod_pico.ino`](../../software/hexapod_pico/hexapod_pico.ino)
   - Edit [`config.h`](../../software/hexapod_pico/config.h) for WiFi credentials (default: SSID="hexapod", password="hexapod_1234")
   - Configure servo pin mappings and calibration offsets as needed

4. **Upload Firmware**:
   - Hold BOOTSEL button while connecting Pico via USB
   - Release button when Pico appears as mass storage device
   - Select the Pico board and upload through Arduino IDE
   - Robot will perform boot-up sequence after upload

### Repository Layout

Nougat is one of several hexapods that share the same firmware and tools. Its hardware lives in this folder; the software is common to all of them.

```text
hexapod/
├── robots/
│   └── nougat/             # This robot: README, 3d print/ (STL + Bambu Studio project), images/
├── images/                 # Images shared by all robots
└── software/
    ├── hexapod_esp32/      # ESP32 firmware (Arduino sketch), shared by all robots
    │   ├── robot.h         # Selects which robot the firmware is built for
    │   └── src/robots/nougat/ # Nougat's robot_config.h and generated motion.h
    ├── hexapod_pico/       # Legacy Raspberry Pi Pico firmware
    └── path_tool/          # Gait generator that produces motion.h
        └── robots/nougat.json # Nougat's geometry and gait parameters
```

See the [ESP32 firmware README](../../software/hexapod_esp32/README.md) for the firmware's file structure.

#### Regenerating the Motion Tables

The gaits in `motion.h` are generated, not hand-written. Every table is derived from [`robots/nougat.json`](../../software/path_tool/robots/nougat.json), which holds the leg mount positions, link lengths, postures and gait parameters. To change one:

1. Install Python with `numpy`, then edit `robots/nougat.json` (or add a generator in `path_tool.py`).
2. From [`software/path_tool`](../../software/path_tool/), run `python generate_motion.py nougat`. It writes `software/hexapod_esp32/src/robots/nougat/motion.h` directly. `lut_generator.ipynb` does the same interactively.
3. Re-upload the firmware.
4. A brand-new table also needs an entry in `motion_config[]` in `motion_control.ino`. See [Adding Custom Motions](../../software/hexapod_esp32/README.md#adding-custom-motions).

### Control Interface

#### Connection

The robot hosts its own Access Point — connect your phone or computer to it directly; it never joins your home router.

| Setting | Default | Where to change it |
| --- | --- | --- |
| WiFi SSID | `hexapod_nougat` (ESP32), `hexapod` (Pico) | `APSSID` in `src/robots/nougat/robot_config.h` |
| WiFi password | `hexapod_1234` | `APPSK` in `config.h` |
| Robot IP | `192.168.4.1` | Fixed by the board's AP (ESP32 and Pico alike) |
| UDP port | `1234` | `UDP_PORT` in `config.h` |
| Web interface | `http://192.168.4.1` | ESP32 firmware only |

1. **Power on the hexapod** - connect the batteries and flip the toggle switch
2. **Join its WiFi network** - the robot runs its stand-up sequence as soon as a client connects
3. **Send commands** to `192.168.4.1:1234`, or open `http://192.168.4.1` for the calibration interface

#### Sending UDP Commands

The hexapod listens on UDP port `1234`. The ESP32 firmware speaks a binary protocol in which the **first byte selects the packet type**; the Pico firmware and older clients use the plain-text commands below.

| Magic  | Packet | Size | Purpose |
| --- | --- | ---- | --- |
| `0xA5` | Motion command  | 6-7 B | Play one of the built-in gait look-up tables |
| `0xA6` | Real-time pose  | 44 B | Stream raw servo positions for all 18 joints |
| `0xA7` | Session control | 6 B  | Enter/leave real-time mode, relax, keep-alive |

A motion command is the magic byte, a command ID, and a 32-bit sequence number — little-endian and unpadded:

```python
import socket
import struct

# 0xA5 (magic), 1 (Walk forward), 0 (sequence number)
packet = struct.pack("<BBI", 0xA5, 1, 0)
sock = socket.socket(socket.AF_INET, socket.SOCK_DGRAM)
sock.sendto(packet, ("192.168.4.1", 1234))
```

Append an optional seventh byte to set the gait speed, in percent of the tuned speed (20-100; `0` leaves it unchanged). The ESP32 firmware starts at **60 %**, so clients sending only the 6-byte form walk at 60 % unless the speed is raised from the **Motion Speed** slider at `http://192.168.4.1`. See the [firmware README](../../software/hexapod_esp32/README.md#motion-speed) for details.

| ID  | Action | Text command |
| --- | --- | --- |
| 0 | Stop and hold position  | `standby` |
| 1 | Walk forward | `walk0` |
| 2 | Walk backward | `walk180` |
| 3 | Walk right at 45° | `walkr45` |
| 4 | Walk right at 90° | `walkr90` |
| 5 | Walk right at 135° | `walkr135` |
| 6 | Walk left at 45° | `walkl45` |
| 7 | Walk left at 90° | `walkl90` |
| 8 | Walk left at 135° | `walkl135` |
| 9 | Fast walk forward | `fastforward` |
| 10  | Fast walk backward | `fastbackward`  |
| 11  | Turn left in place | `turnleft` |
| 12  | Turn right in place | `turnright` |
| 13  | Climbing gait forward | `climbforward`  |
| 14  | Climbing gait backward  | `climbbackward` |
| 15  | Body rotation — pitch | `rotatex` |
| 16  | Body rotation — roll | `rotatey` |
| 17  | Body rotation — yaw | `rotatez` |
| 18  | Body twist motion | `twist` |

The real-time pose (`0xA6`) and session control (`0xA7`) packets, their field layouts and the failsafe behaviour are documented in the [ESP32 UDP command reference](../../software/hexapod_esp32/README.md#udp-command-reference).

**Text commands:** both firmwares accept plain command strings (the `Text command` column above), e.g. `sock.sendto(b":walk0:", ("192.168.4.1", 1234))`. The `:` delimiters are optional — leading delimiters are skipped and the command ends at the first one. This is the only interface on the Pico; new ESP32 clients should use the binary protocol.

**Boot Behavior:** The robot automatically performs a boot sequence (stands up) when a client connects to its WiFi network.

### Over-The-Air (OTA) Updates

Both ESP32 and Pico support wireless firmware updates:

1. **Power on** the robot and **connect** to its WiFi network
2. In Arduino IDE, go to **Tools → Port → Network Ports**
3. Select the hexapod from network ports
4. Click **Upload** as normal

**Important Notes:**

- For ESP32: OTA survives binary motion commands (`0xA5`), but is switched off once the robot enters real-time mode or receives a text command. Reboot to re-enable it.
- For Pico: Ensure Flash Size includes "FS: 1MB" in board settings for OTA to work.

### Troubleshooting

**Upload fails:**

- Check USB cable (must support data transfer)
- Try different USB port
- Ensure correct board and port selected
- For ESP32: Hold BOOT button during upload

**Servos not responding:**

- Verify battery voltage (should be 7.4V nominal for 2S Li-ion setup)
- Check all servo connections match the wiring diagram
- For ESP32: Verify PCA9685 I2C addresses (default: 0x40 left, 0x41 right)
- For ESP32: Check enable pins (GPIO 19 for left, GPIO 26 for right)
- Test individual servos using `posture_calibration()` function
- Confirm servo pin mappings in `config.h` match your wiring

**WiFi connection issues:**

- Verify the SSID (`src/robots/nougat/robot_config.h`) and password (`config.h`) (default: hexapod_nougat/hexapod_1234 for ESP32, hexapod/hexapod_1234 for Pico)
- The hexapod creates an **Access Point** - connect to it, don't look for it on your router
- Ensure your device supports 2.4GHz WiFi (5GHz not supported)
- Default IP is always `192.168.4.1` when connected to the hexapod's AP

**OTA not working:**

- For ESP32: real-time mode and text commands turn OTA off - reboot to re-enable
- Ensure you're connected to the hexapod's WiFi network
- Check firewall settings on your computer
- For Pico: Verify Flash Size setting includes "FS: 1MB"

### Android App

Control your hexapod directly from your Android smartphone:

<a href="https://play.google.com/store/apps/details?id=com.rookiedev.hexapod">
  
</a>

The app provides an intuitive interface to:

- Connect to your hexapod's WiFi network
- Control movement with on-screen buttons
- Execute all available motion commands
- Monitor connection status

**Requirements:** Android device with WiFi capability

### Desktop Control Software

The [Hexapod Link](https://github.com/rookidroid/hexapod-link) can drive the ESP32 version live through the real-time pose streaming protocol.

## Calibration Guide

Proper calibration is **critical** for smooth walking. Take your time with this step!

### Understanding Servo Positions

All servos should be at 90° (neutral position) when the legs are in the reference positions shown below.

### Calibration Procedure

The ESP32 firmware includes a **web-based calibration interface** that makes the calibration process much easier - no need to repeatedly edit code and re-upload firmware!

_For the Pico version, adjust `left_offset_ticks` and `right_offset_ticks` in [`config.h`](../../software/hexapod_pico/config.h) and re-upload the firmware instead._

#### Step 1: Access the Calibration Interface

1. **Upload Firmware**: Flash the code to your controller with default offset values
2. **Power On**: Connect batteries and turn on the hexapod
3. **Connect to WiFi**: Join the hexapod's WiFi network (default SSID: `hexapod_nougat`)
4. **Open Browser**: Navigate to `http://192.168.4.1`

Calibration Web Interface

#### Step 2: Enter Calibration Mode

1. Click the **"Enter Calibration Mode"** button
   - The hexapod will stop motion execution
   - All current offset values will be loaded
   - A grid showing all 6 legs (18 servos) will appear

2. **Check Leg Positions**: Compare each leg with the reference images below
   - **Coxa (hip) joint**: Should be perpendicular to body
   - **Femur (thigh) joint**: Should be horizontal
   - **Tibia (shin) joint**: Should form 90° angle with femur
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

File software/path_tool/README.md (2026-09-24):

# Path Tool

Generates the motion look-up tables (`motion.h`) that the firmware plays back. One shared set of path generators covers every robot. What differs between robots is data, and it lives in `robots/<name>.json`.

## Files

- `robots/<name>.json`: one robot's leg mount positions and angles, link lengths, servo range, standby/laydown postures and gait parameters
- `generate_motion.py`: builds every gait for a robot and writes its `motion.h`
- `lut_generator.ipynb`: interactive version of `generate_motion.py`, for inspecting postures and paths
- `path_tool.py`: path generators for walking, fast walking, turning, climbing, body rotations and the stand-up sequence
- `path_lib.py`: inverse kinematics and path primitives

## Usage

Requires Python 3 with `numpy`.

```bash
cd software/path_tool
python generate_motion.py mochi      # one robot
python generate_motion.py --all      # every robot in robots/
```

The header is written straight into the firmware, at `../hexapod_esp32/src/robots/<name>/motion.h`. Re-upload the firmware to use it. Pass `-o <file>` to write it somewhere else instead.

## Adding a Robot

1. Copy an existing `robots/<name>.json` to `robots/<new>.json` and fill in the new geometry.
2. Run `python generate_motion.py <new>`.
3. In the firmware, add `src/robots/<new>/robot_config.h` and a `ROBOT_<NEW>` entry in `robot.h` and `motion.h`.

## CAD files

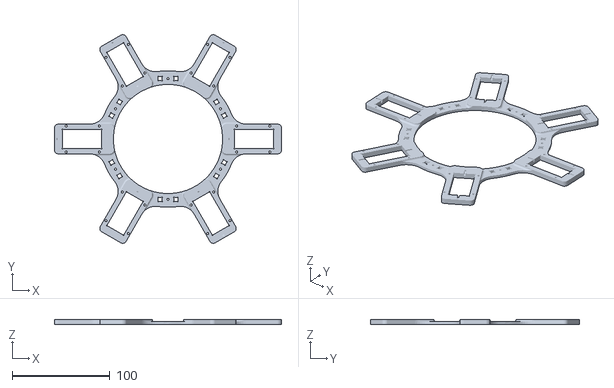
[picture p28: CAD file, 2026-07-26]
robots/macaroon/3d print/body/body_top.STL
232.8 x 214.0 x 5.00

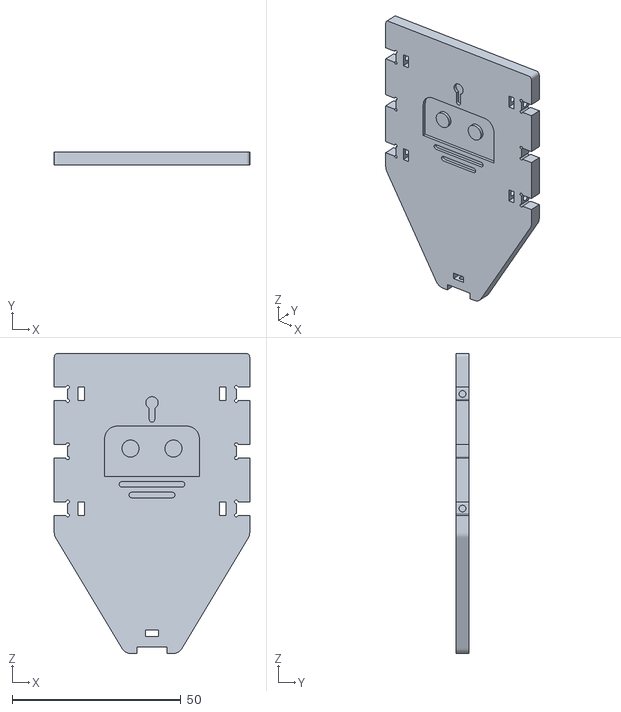
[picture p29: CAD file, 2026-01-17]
robots/macaroon/3d print/foot/foot_ground.STL
58.0 x 4.00 x 89.0

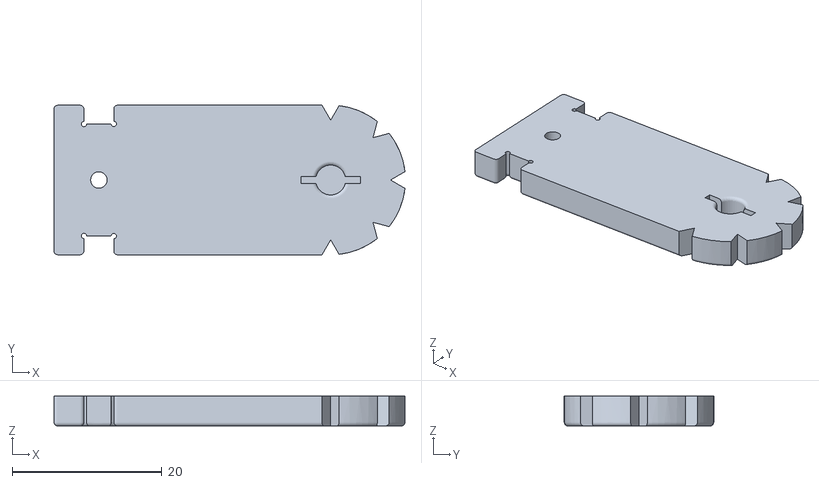
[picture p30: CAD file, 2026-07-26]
robots/macaroon/3d print/joint/joint_bottom.STL
46.9 x 20.0 x 4.00

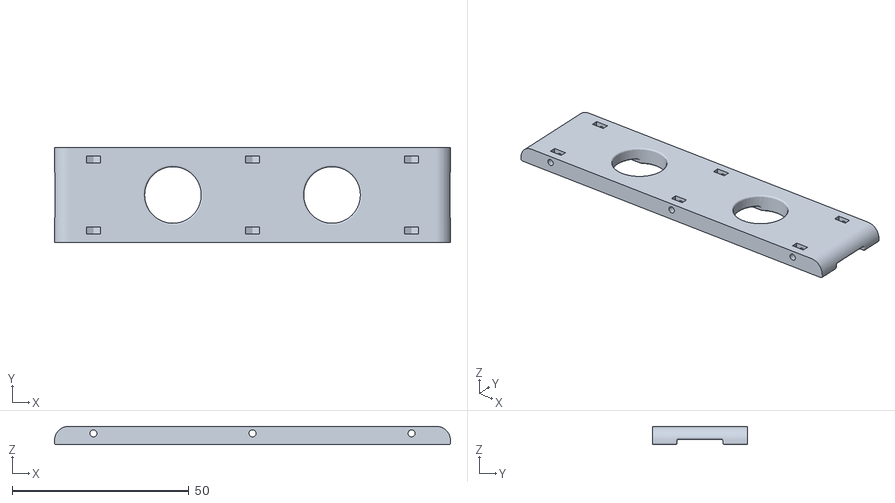
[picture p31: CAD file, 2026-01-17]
robots/macaroon/3d print/leg/leg_side.STL
112.0 x 27.0 x 5.20

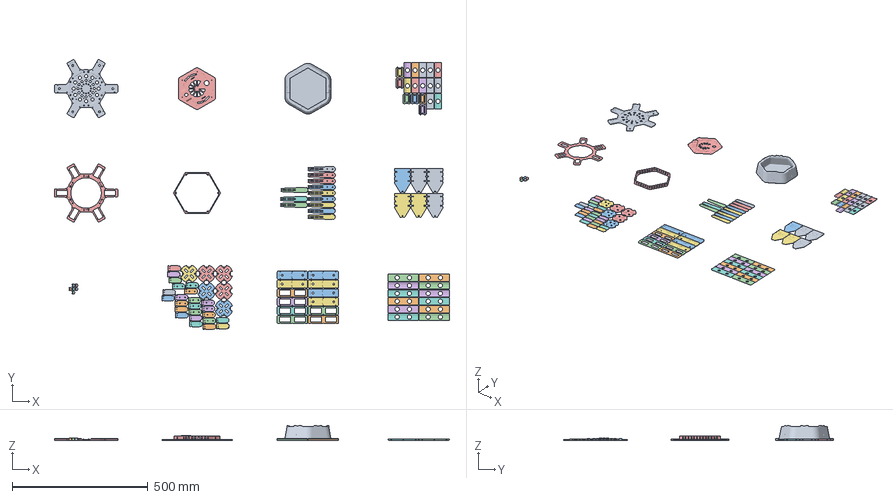
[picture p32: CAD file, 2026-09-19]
robots/macaroon/3d print/macaroon.3mf
1453.4 x 992.9 x 54.0 mm
body_base.STL
leg_side.STL x 12
leg_bottom.STL x 6
joint_cross.STL x 6
foot_ground.STL x 6
foot_top.STL x 6
leg_top.STL x 6
body_servo_side.STL x 12
joint_top.STL x 12
body_head.STL
fence.STL
body_top.STL
joint_bottom.STL x 12
foot_bottom.STL x 6
body_battery.STL
body_side.STL x 6
foot_tip.STL x 6

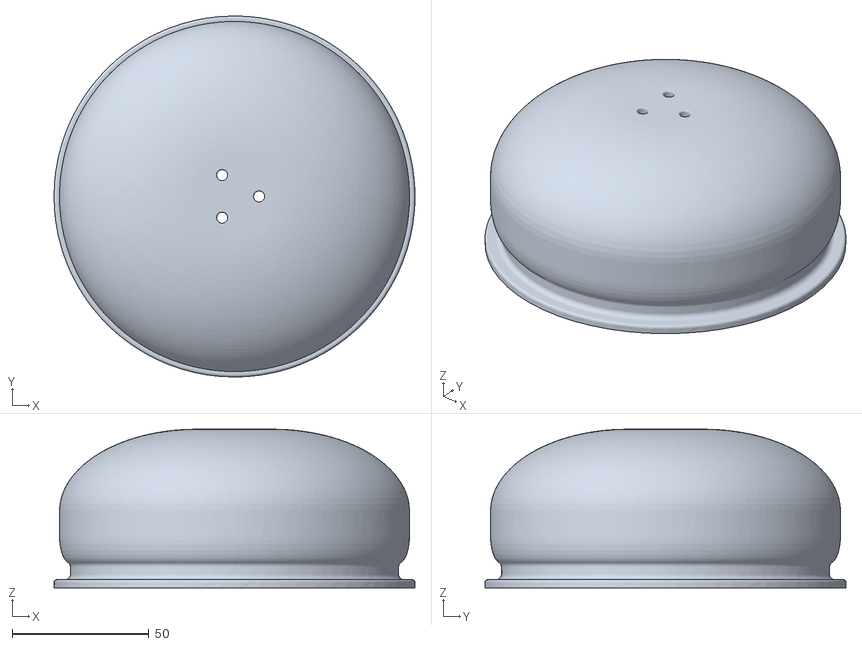
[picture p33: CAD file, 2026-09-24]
robots/mochi/3d print/body/body_head.STL
132.0 x 132.0 x 58.0

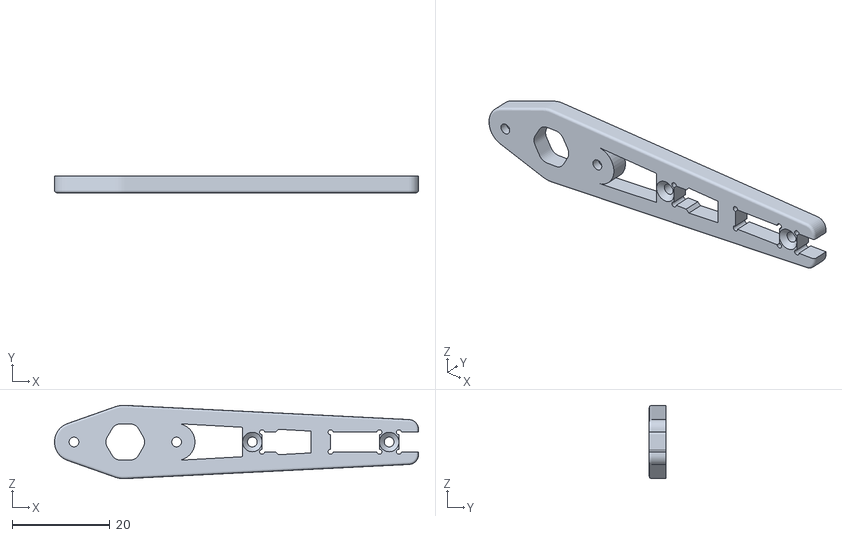
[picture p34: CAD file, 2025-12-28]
robots/mochi/3d print/foot/foot_top.STL
74.5 x 3.40 x 15.0

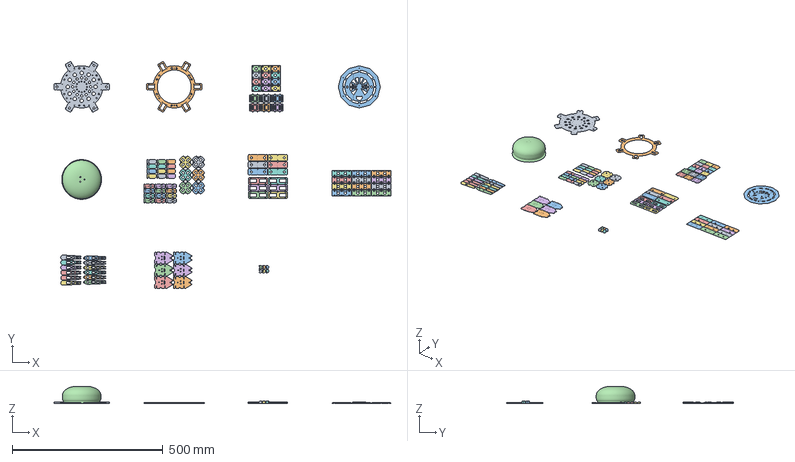
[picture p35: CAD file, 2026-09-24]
robots/mochi/3d print/hexapod_mochi.3mf
1118.3 x 752.4 x 58.0 mm
body_base.STL
body_top.STL
body_battery.STL
body_head.STL
body_servo_side.STL x 12
body_side.STL x 6
joint_bottom.STL x 12
joint_top.STL x 12
joint_cross.STL x 6
leg_bottom.STL x 6
leg_top.STL x 6
leg_side.STL x 12
foot_bottom.STL x 6
foot_ground.STL x 6
foot_top.STL x 6
foot_tip.STL x 6

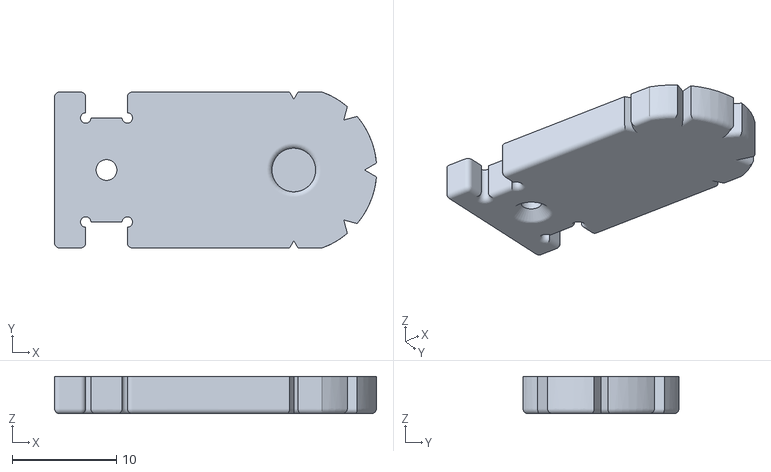
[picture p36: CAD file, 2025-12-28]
robots/mochi/3d print/joint/joint_bottom.STL
30.9 x 15.0 x 3.60

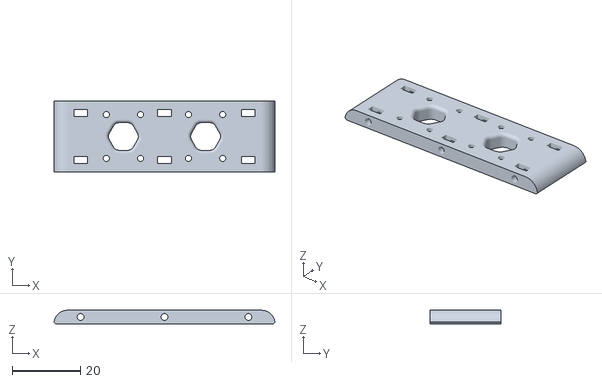
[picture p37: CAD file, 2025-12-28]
robots/mochi/3d print/leg/leg_side.STL
64.5 x 20.8 x 4.00

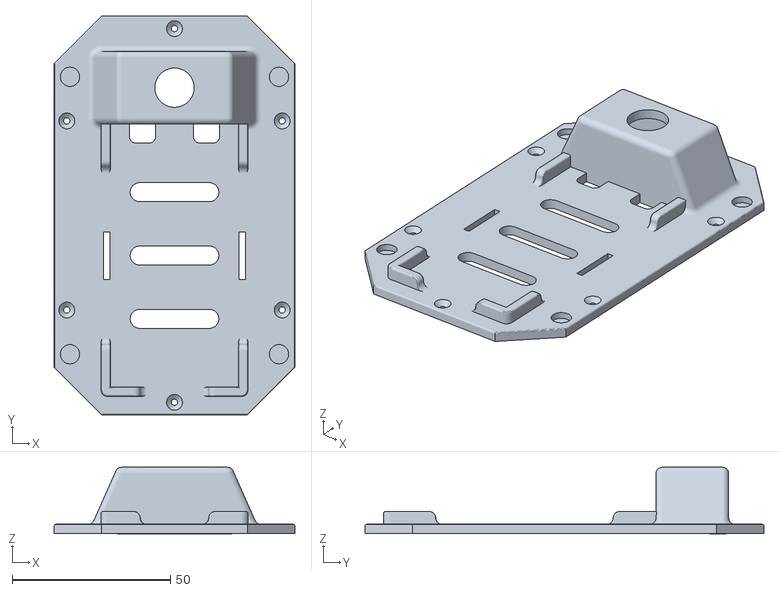
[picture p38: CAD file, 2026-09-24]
robots/nougat/3d print/body/body_battery.STL
76.0 x 126.0 x 21.0

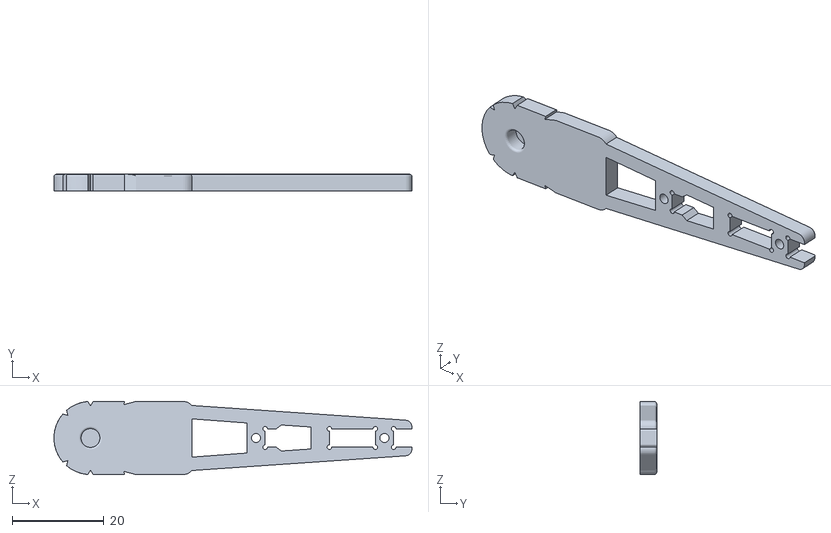
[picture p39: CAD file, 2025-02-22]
robots/nougat/3d print/foot/foot_bottom.STL
78.0 x 3.60 x 16.0

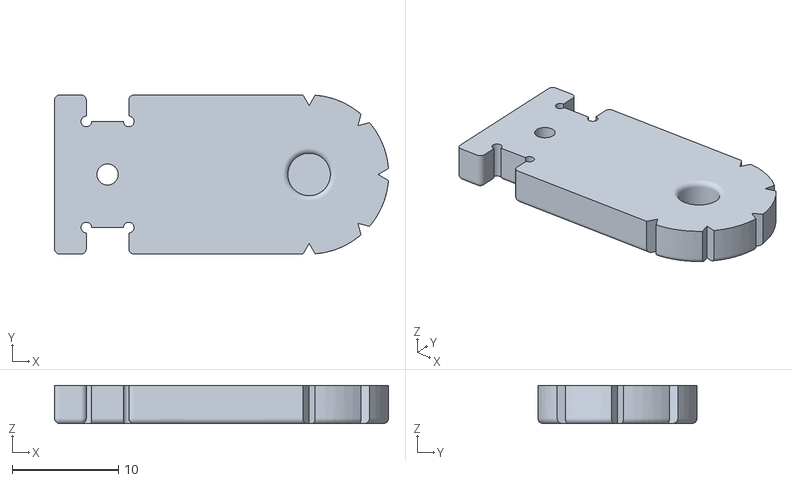
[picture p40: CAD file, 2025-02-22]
robots/nougat/3d print/joint/joint_bottom.STL
31.5 x 15.0 x 3.60

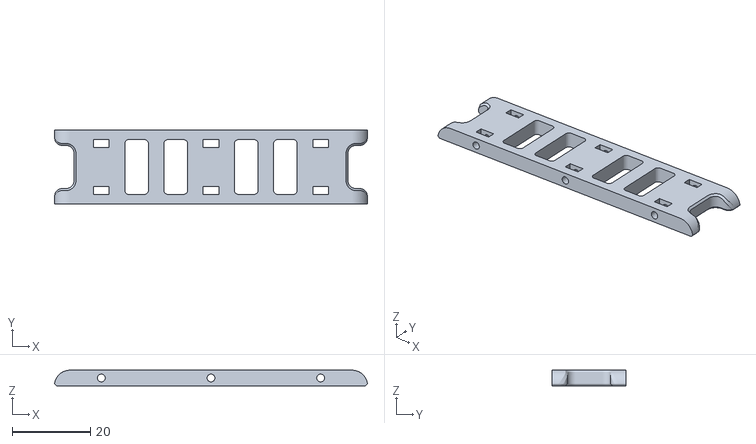
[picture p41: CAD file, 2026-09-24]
robots/nougat/3d print/leg/leg_side.STL
79.9 x 19.0 x 4.00

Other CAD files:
robots/nougat/3d print/nougat.3mf
robots/macaroon/3d print/body/fence.STL
robots/macaroon/3d print/foot/foot_bottom.STL
robots/macaroon/3d print/joint/joint_cross.STL
robots/macaroon/3d print/body/body_base.STL
robots/macaroon/3d print/body/body_battery.STL
robots/macaroon/3d print/body/body_head.STL
robots/macaroon/3d print/body/body_servo_side.STL
robots/macaroon/3d print/body/body_side.STL
robots/macaroon/3d print/foot/foot_tip.STL
robots/macaroon/3d print/foot/foot_top.STL
robots/macaroon/3d print/joint/joint_top.STL
robots/macaroon/3d print/leg/leg_bottom.STL
robots/macaroon/3d print/leg/leg_top.STL
robots/mochi/3d print/body/body_base.STL
robots/mochi/3d print/body/body_battery.3mf
robots/mochi/3d print/body/body_servo_side.STL
robots/mochi/3d print/body/body_side.STL
robots/mochi/3d print/body/body_top.STL
robots/mochi/3d print/foot/foot_bottom.STL
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

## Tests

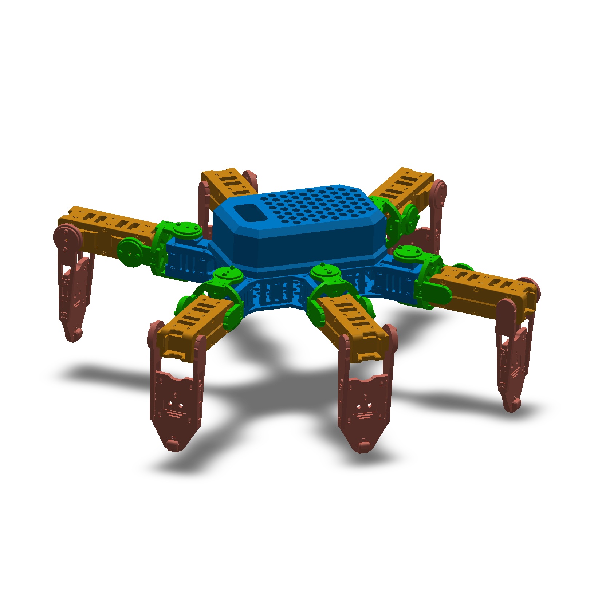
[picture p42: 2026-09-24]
robots/nougat/images/calibration_1.jpg

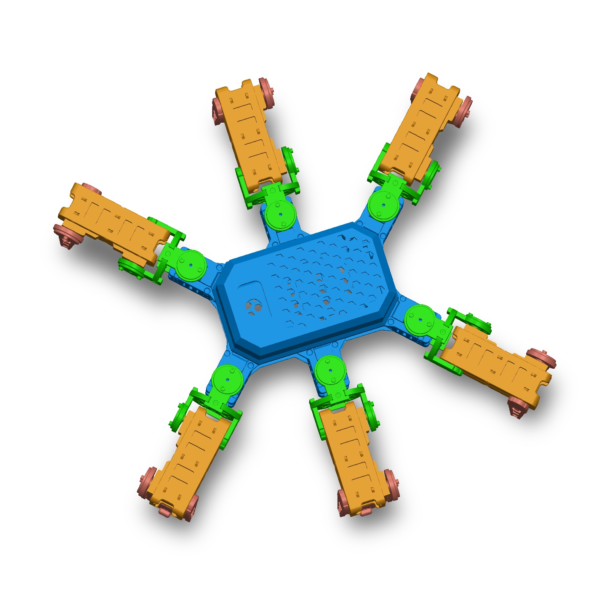
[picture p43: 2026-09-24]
robots/nougat/images/calibration_2.jpg

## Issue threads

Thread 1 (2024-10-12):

Incorred i2c address for left and right PCA9685

ikigai-festuccia-simone, 2024-10-12:
there is a problem with the wiring schema and the code for arduino board regarding the addressing of the 2 controllers

on the wiring schema is marked to solder the a5 connector that's dec 32 hex 20

in the code for arduino board reference is 41 for the second channel, in this way half of the hexapod doesnt move. changing the address to x60 will have all the servos to move correctly!

another issue is that on the source code the standard address is left for the left legs and override i2c is for the right, in the wiring schema is the opposite.

rookiepeng, 2024-10-13:
Thanks for pointing out the mistakes. I have corrected the diagram

Closed 2024-10-13.

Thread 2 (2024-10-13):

leg joint mounting scheme should be 3x (L) and 3x (R) instead of 6x

ikigai-festuccia-simone, 2024-10-13:
hi, since I see you are pretty active on the project, I would like to point out another thing that can lead to confusion on the mounting scheme.

there is a mounting guide that show 6 time the same joint but they should be two different series for have the first servo to move the joint allways on top.

rookiepeng, 2024-10-14:
Thanks! I adjusted the readme to address this

Closed 2024-10-14.

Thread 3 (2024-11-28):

Small raiser for Servo's

SammieSamSam, 2024-11-28:
I came to the conclusion that for some servo's, the servo becomes slightly raised and not in line with the print. so i made 2mm raisers that are really small, and go in between the servo and the legs. i put the STL and some images in the attachments in the form of a zip file :) hope it helps some people that want to build this hexapod too!
[accessory_small_spacer_mg90s.zip](https://github.com/user-attachments/files/17945919/accessory_small_spacer_mg90s.zip)

rookiepeng, 2024-11-29:
I already have "accessory_spacer_mg90s.STL" in the model. Doesn't it work?

While using MG92B servo, the spacer is not needed. If you use MG90S, the spacer is needed.

SammieSamSam, 2024-12-03:
I use the MG90s with "accessory_spacer_mg90s.STL" but the servo moves within the leg if i don't also use the small spacers i made (they go in between the top of the servo and the leg like in the image i will also send again)
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
I'm not sure if it is an issue with the certain servo's I got having extra space between the screw holes or it being an issue with every MG90s but this spacer works for me in combination with the other spacer :)

rookiepeng, 2024-12-03:
This is strange. I guess the servo you use has different size with the one I use. Anyway, I will add your stl file into the repo. Thank you!

Closed 2024-12-07.

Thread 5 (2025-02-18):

about two XL4005 chips

463728946, 2025-02-18:
Hello, I really like your project and am currently trying to make one myself. I'd like to ask if two XL4005 chips are necessary. I carefully checked the specifications and it seems that one XL4005 can drive two PCA9685 chips. The full - load current for 16 servos is probably around 3A, and the power supply from two 18650 batteries is also only 3A.

463728946, 2025-02-18:
Additionally, why isn't the extra power supply for PCA9685 connected to the dedicated interface in the middle, but through the PWM pins? Is there any special reason?

My English is very poor, I hope my expression did not offend you

rookiepeng, 2025-02-18:
2 XL4005 probably not necessary while the hexapod operating without obstacles. The dedicated interface in the middle of the PCA9685 and the PWM power pins are actually connected. I did this for convenience.

For the current version of the Hexapod, there are a few issues, especially the servos are a bit weak. I am working on a updated version and will publish the design files within a week.

463728946, 2025-02-19:
I'm really looking forward to the new version. Will the new version not use MG90S? I've bought a whole lot of them.

Closed 2025-02-21.

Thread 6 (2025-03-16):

path_tool v1

463728946, 2025-03-16:
May I ask if the current motion.h can be used directly, or if it is necessary to run path_tool to customize it?

rookiepeng, 2025-03-18:
Yes. The motion.h in v2 source code works for Hexapod v2, and motion.h in v1 source code works for Hexapod v1.

463728946, 2025-03-19:
I'm still using v1 since the servos of v2 are too expensive.

I've come across a really tricky problem.

I run `posture_calibration`, and all joints are set to 350° in the mid position. Everything looks fine.
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

But when I run `boot_up_motion` or `Mode_Standby`, the angles of right_center_joint2 and left_center_joint2 go down (red arrow), while the other four go up normally (blue arrow)
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

I elevated it and tried walking. The movements look coordinated.

I've also carefully checked their front and back.
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

Closed 2025-03-18.

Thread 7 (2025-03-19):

The angle left_leg joint2 and right_leg joint2 is abnormal

463728946, 2025-03-19:
I run `posture_calibration`, and all joints are set to 350° in the mid position. Everything looks fine.
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

But when I run `boot_up_motion` or `Mode_Standby`, the angles of right_center_joint2 and left_center_joint2 go down (red arrow), while the other four go up normally (blue arrow)
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

I elevated it and tried walking. The movements look coordinated.

I've also carefully checked their front and back.
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

Closed 2025-03-19.

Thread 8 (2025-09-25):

Assembly/URDF files

IannoIITR, 2025-09-25:
This is a really interesting project, thanks for sharing the model files. Could you also share the URDF or assembly file for this? I was trying to import this in a simulator to test some control algorithms.

IannoIITR, 2025-09-27:
Hey, just wanted to follow up to check if you could share either the urdf or assembly file for the project.

rookiepeng, 2025-09-28:
Hi, I currently don't have a plan to share the original design file. Thanks

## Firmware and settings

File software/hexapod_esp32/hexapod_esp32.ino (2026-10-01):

/**

  Hexapod -- A 3D Printed Hexapod Robot

  - Copyright (C) 2024 - PRESENT  rookidroid.com
  - E-mail: info@rookidroid.com
  - Website: https://rookidroid.com/

                        **
                       ****
                        **
                        **
                        **
                        **

        **********************************
      **************************************
     ****************************************
     ********      ************      ********
     *******        **********        *******
     *******        **********        *******
     ********      ************      ********
     ****************************************
     ****************************************
     ****************************************
     ****************************************


            **************************

                ******************

*/

/** OTA */
#include <ArduinoOTA.h>

/** Shared state and module interfaces */
#include "hexapod.h"

/** Motion Path LUT */
#include "motion.h"

// ============================================================================
// System state
// ============================================================================
// Declared in hexapod.h; the modules read and write these through that header.

volatile bool ota_mode = true;       // OTA updates enabled until first command
bool wifi_connected = false;         // WiFi AP connection status
bool boot_sequence_executed = false; // Boot sequence completion flag
volatile bool trigger_boot_sequence =
    false;                     // Boot trigger from WiFi event (volatile for ISR)
bool calibration_mode = false; // Calibration mode flag

volatile int next_motion_idx = CMD_STANDBY; // Motion requested over UDP

volatile unsigned long last_udp_packet_time = 0; // Tracks last UDP packet for failsafe

volatile uint8_t motion_speed_pct = MOTION_SPEED_DEFAULT_PCT; // LUT playback speed

/**
   @brief Set the LUT playback speed. Called from the UDP task and the web
   interface; a single byte, so the store is atomic.
   @param pct Speed in percent of the tuned frame rate
*/
void setMotionSpeed(int pct)
{
  motion_speed_pct = constrain(pct, MOTION_SPEED_MIN_PCT, 100);
}

/**
   @brief Initialize system: WiFi AP, OTA, calibration, PWM drivers, UDP and
   the web interface.
*/
void setup()
{
  Serial.begin(115200);
  while (!Serial && millis() < 3000)
  {
    ; // Wait for serial port to connect, timeout after 3s
  }
  Serial.println("\n=== Hexapod Robot Initializing ===");
  Serial.println("Robot: " ROBOT_NAME ", firmware " FIRMWARE_VERSION " (" FIRMWARE_BUILD ")");

  setupWiFi();
  setupOta();

  // Offsets first: every servo position written afterwards is shifted by them.
  setupCalibration();
  setupServos();

  setupUdp();
  setupWebServer();

  Serial.println("=== Initialization Complete ===");

  // posture_calibration();
}

/**
   @brief Main loop: run the boot sequence once, then service the web
   interface, OTA and the motion engine without blocking.
*/
void loop()
{
  // Handle boot sequence trigger from WiFi event
  if (trigger_boot_sequence && !boot_sequence_executed)
  {
    boot_sequence_executed = true;
    trigger_boot_sequence = false;
    boot_up_motion(lut_standup_length, lut_standup);
  }

  web_server.handleClient();

  if (ota_mode)
  {
    ArduinoOTA.handle();
  }

  // Motion commands wait until the robot has stood up.
  if (boot_sequence_executed)
  {
    serviceMotionEngine();
  }

  delay(1); // Yield to the WiFi and UDP tasks
}

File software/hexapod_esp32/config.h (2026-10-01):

/**

  Configuration file

  - Copyright (C) 2024 - PRESENT  rookidroid.com
  - E-mail: info@rookidroid.com
  - Website: https://rookidroid.com/

                        **
                       ****
                        **
                        **
                        **
                        **

        **********************************
      **************************************
     ****************************************
     ********      ************      ********
     *******        **********        *******
     *******        **********        *******
     ********      ************      ********
     ****************************************
     ****************************************
     ****************************************
     ****************************************


            **************************

                ******************

*/

#ifndef CONFIG_H
#define CONFIG_H

#include <Arduino.h>

// Robot-specific settings (DELAY_MS, APSSID) come from the robot picked here
#include "robot.h"

#define SERVOMIN 102  // Minimum value, 0 deg
#define SERVOMID 307  // Middle value, 90 deg
#define SERVOMAX 512  // Maximum value, 180 deg

/** Real-time pose streaming */
// Control cycle period while streaming poses (ms). 20 ms -> 50 Hz.
#define REALTIME_PERIOD_MS 20
// Drop out of real-time mode if no packet arrives within this window (ms).
#define REALTIME_TIMEOUT_MS 1000
// Default per-joint slew limit, in ticks per control cycle. Caps how fast a
// streamed pose can be chased so a large jump cannot slam the servos.
#define REALTIME_DEFAULT_MAX_STEP 8

/** Motion LUT playback */
// Fall back to standby if no UDP packet arrives within this window (ms). Clients
// driving the LUT engine must repeat their motion command faster than this.
#define MOTION_TIMEOUT_MS 500
// LUT playback speed, as a percentage of the robot's tuned frame rate
// (DELAY_MS). Slower speeds blend between LUT frames, so the servos keep moving
// smoothly; faster is not allowed.
#define MOTION_SPEED_MIN_PCT 20
#define MOTION_SPEED_DEFAULT_PCT 60

/** Debugging */
// 1 = log and echo every low-rate UDP packet on the serial port
#ifndef HEXAPOD_DEBUG
#define HEXAPOD_DEBUG 0
#endif

/** PCA9685 PWM drivers */
// I2C addresses for the left and right servo banks
const uint8_t LEFT_PWM_ADDRESS = 0x40;   // Left side servos (3 legs)
const uint8_t RIGHT_PWM_ADDRESS = 0x41;  // Right side servos (3 legs)

// GPIO pins for PWM driver enable control (active LOW)
const uint8_t LEFT_PWM_ENABLE_PIN = 19;   // Enable left legs PWM driver
const uint8_t RIGHT_PWM_ENABLE_PIN = 26;  // Enable right legs PWM driver

// PWM frequency for servo control signals (Hz)
const uint16_t SERVO_PWM_FREQ = 50;

// I2C bus clock (Hz). The PCA9685 supports up to 1 MHz; at the 100 kHz default
// writing all 18 servos takes ~10 ms, which stretched every LUT frame.
const uint32_t I2C_CLOCK_HZ = 400000;

// PCA9685 internal oscillator (Hz). Nominally 25 MHz, but individual chips vary
// by a few percent; measure a pulse and adjust if servo angles are off.
const uint32_t PCA9685_OSC_HZ = 25000000;

// Delay between individual servo movements during boot (ms)
const uint16_t SERVO_INIT_DELAY_MS = 50;

// Step size for smooth transitions between positions
const uint8_t TRANSITION_TICK_STEP = 6;

// Servo connections to the PCA9685 driver
// {{leg1_join1, leg1_join2, leg1_join3},
//  {leg2_join1, leg2_join2, leg2_join3},
//  {leg3_join1, leg3_join2, leg3_join3}}
static const int left_legs[3][3] = { { 1, 2, 3 }, { 5, 6, 7 }, { 9, 8, 10 } };
static const int right_legs[3][3] = { { 10, 9, 8 }, { 13, 14, 15 }, { 7, 6, 5 } };

// Offset to correct the installation error. Offset value is the number of ticks.
// These are the live calibration values: the web interface edits them and
// calibration.ino restores them from flash at boot. They stay `static` because
// the sketch tabs compile as a single translation unit.
static int left_offset_ticks[3][3] = { { 0, 0, 0 }, { 0, 0, 0 }, { 0, 0, 0 } };
static int right_offset_ticks[3][3] = { { 0, 0, 0 }, { 0, 0, 0 }, { 0, 0, 0 } };

// Largest calibration offset accepted from the web interface or from flash
// (ticks, ~44 deg). Anything bigger is a typo or corrupt data, not a trim.
const int CALIBRATION_MAX_OFFSET = 100;

/** Calibration storage (NVS via Preferences) */
#define CALIBRATION_NVS_NAMESPACE "hexapod"
#define CALIBRATION_NVS_KEY "offsets"
const uint8_t CALIBRATION_VERSION = 1;  // Bump when the stored layout changes

/** Legacy EEPROM layout -- read once to migrate old calibrations to NVS */
const uint16_t EEPROM_SIZE = 64;        // Total EEPROM size to allocate
const uint16_t EEPROM_MAGIC = 0xABCD;   // Magic number to verify valid data
const uint16_t EEPROM_ADDR_MAGIC = 0;   // Address for magic number
const uint16_t EEPROM_ADDR_LEFT = 2;    // Address for left offsets
const uint16_t EEPROM_ADDR_RIGHT = 20;  // Address for right offsets (after 18 bytes)
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

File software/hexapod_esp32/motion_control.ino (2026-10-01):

/**

  Servo output and motion playback -- the only path to the PCA9685 drivers

  - Copyright (C) 2024 - PRESENT  rookidroid.com
  - E-mail: info@rookidroid.com
  - Website: https://rookidroid.com/

*/

#include <Wire.h>

#include "hexapod.h"
#include "motion.h"

// PWM driver instances for left and right servo banks
Adafruit_PWMServoDriver left_pwm = Adafruit_PWMServoDriver(LEFT_PWM_ADDRESS);
Adafruit_PWMServoDriver right_pwm = Adafruit_PWMServoDriver(RIGHT_PWM_ADDRESS);

// Motion configuration table - add new motions here. The index of each entry
// is its RobotCommand ID, so the order must match protocol.h.
const MotionConfig motion_config[] = {
    {"standby", lut_standby_length, lut_standby},
    {"walk0", lut_walk_0_length, lut_walk_0},
    {"walk180", lut_walk_180_length, lut_walk_180},
    {"walkr45", lut_walk_r45_length, lut_walk_r45},
    {"walkr90", lut_walk_r90_length, lut_walk_r90},
    {"walkr135", lut_walk_r135_length, lut_walk_r135},
    {"walkl45", lut_walk_l45_length, lut_walk_l45},
    {"walkl90", lut_walk_l90_length, lut_walk_l90},
    {"walkl135", lut_walk_l135_length, lut_walk_l135},
    {"fastforward", lut_fast_forward_length, lut_fast_forward},
    {"fastbackward", lut_fast_backward_length, lut_fast_backward},
    {"turnleft", lut_turn_left_length, lut_turn_left},
    {"turnright", lut_turn_right_length, lut_turn_right},
    {"climbforward", lut_climb_forward_length, lut_climb_forward},
    {"climbbackward", lut_climb_backward_length, lut_climb_backward},
    {"rotatex", lut_rotate_x_length, lut_rotate_x},
    {"rotatey", lut_rotate_y_length, lut_rotate_y},
    {"rotatez", lut_rotate_z_length, lut_rotate_z},
    {"twist", lut_twist_length, lut_twist}};

const size_t motion_config_count =
    sizeof(motion_config) / sizeof(motion_config[0]);

static_assert(sizeof(motion_config) / sizeof(motion_config[0]) == CMD_COUNT,
              "motion_config[] needs exactly one entry per RobotCommand");

Pose pose_current;

// ============================================================================
// Motion engine state
// ============================================================================
// The engine is ticked from loop() and never blocks: each call does at most one
// control step, so the web interface, OTA and the failsafes stay responsive
// while the robot walks. Its mode and phase types live in hexapod.h.

static EngineMode engine_mode = ENGINE_LUT;
static LutPhase lut_phase = LUT_TO_STANDBY;
static int active_motion = CMD_STANDBY;
static int frame_idx = 0;
static int frame_frac = 0; // Progress toward the next frame, in percent (0-99)
static unsigned long last_tick_ms = 0;

/**
   @brief Bring up the PWM drivers and their enable pins.

   The enable pins are configured before the drivers are switched on so a pose
   packet arriving mid-boot cannot drive an unconfigured pin.
*/
void setupServos()
{
  // Initialize the PCA9685 PWM drivers
  Serial.println("Initializing PWM drivers...");
  left_pwm.begin();
  left_pwm.setOscillatorFrequency(PCA9685_OSC_HZ);
  left_pwm.setPWMFreq(SERVO_PWM_FREQ);

  right_pwm.begin();
  right_pwm.setOscillatorFrequency(PCA9685_OSC_HZ);
  right_pwm.setPWMFreq(SERVO_PWM_FREQ);

  // After begin(), which (re)starts the bus at its default speed.
  Wire.setClock(I2C_CLOCK_HZ);
  Serial.println("PWM drivers initialized");

  // Configure PWM driver enable pins (active LOW)
  pinMode(LEFT_PWM_ENABLE_PIN, OUTPUT);
  pinMode(RIGHT_PWM_ENABLE_PIN, OUTPUT);

  setPwmEnabled(true);
}

/**
   @brief Write one servo, applying its calibration offset and range clamp.
   @param leg_idx Leg in LUT order (0-2 right, 3-5 left)
   @param joint_idx Joint (coxa, femur, tibia)
   @param ticks Uncalibrated position in servo ticks
*/
void writeServo(int leg_idx, int joint_idx, int ticks)
{
  // Clamp after adding the calibration offset. LUT values are in range by
  // construction, but streamed poses are not, and an out-of-range tick drives
  // the servo into its mechanical stop where it stalls and heats.
  if (leg_idx < 3)
  {
    right_pwm.setPWM(right_legs[leg_idx][joint_idx], 0,
                     constrain(ticks + right_offset_ticks[leg_idx][joint_idx],
                               SERVOMIN, SERVOMAX));
  }
  else
  {
    left_pwm.setPWM(left_legs[leg_idx - 3][joint_idx], 0,
                    constrain(ticks + left_offset_ticks[leg_idx - 3][joint_idx],
                              SERVOMIN, SERVOMAX));
  }
  pose_current[leg_idx][joint_idx] = ticks;
}

/**
   @brief Write a whole-body pose to all 18 servos.
   @param pose Positions for all 6 legs (3 joints each)
*/
void writePose(const Pose pose)
{
  for (int leg_idx = 0; leg_idx < 3; leg_idx++)
  {
    for (int joint_idx = 0; joint_idx < 3; joint_idx++)
    {
      writeServo(leg_idx, joint_idx, pose[leg_idx][joint_idx]);
      writeServo(leg_idx + 3, joint_idx, pose[leg_idx + 3][joint_idx]);
    }
  }
}

/**
   @brief The calibration posture: every joint at its mechanical middle.
*/
static void neutralPose(Pose pose)
{
  for (int leg_idx = 0; leg_idx < 6; leg_idx++)
  {
    for (int joint_idx = 0; joint_idx < 3; joint_idx++)
    {
      pose[leg_idx][joint_idx] = SERVOMID;
    }
  }
}

/**
   @brief Set all servos to neutral position using calibration offsets.

   Jumps straight there. Once the motion engine runs, calibration mode eases
   into this posture instead.
*/
void posture_calibration()
{
  Pose neutral;
  neutralPose(neutral);
  writePose(neutral);
}

/**
   @brief Execute boot sequence to stand up the robot.

   Blocking, but it runs once, before the motion engine takes over.
   @param lut_size Number of steps in the motion sequence
   @param lut Look-up table with servo positions for each step
*/
void boot_up_motion(int lut_size, const Pose lut[])
{
  Serial.println("Starting boot sequence...");

  // Phase 1: Initialize servos to starting position
  // Gradual activation prevents current spikes and sudden movements
  for (int leg_idx = 0; leg_idx < 3; leg_idx++)
  {
    for (int joint_idx = 0; joint_idx < 3; joint_idx++)
    {
      writeServo(leg_idx, joint_idx, lut[0][leg_idx][joint_idx]);
      delay(SERVO_INIT_DELAY_MS);
      writeServo(leg_idx + 3, joint_idx, lut[0][leg_idx + 3][joint_idx]);
      delay(SERVO_INIT_DELAY_MS);
    }
  }

  // Phase 2: Execute stand-up motion sequence
  // Step through each position in the LUT to stand up robot
  for (int lut_idx = 0; lut_idx < lut_size; lut_idx++)
  {
    writePose(lut[lut_idx]);
    delay(DELAY_MS);
  }

  Serial.println("Boot sequence complete");
}
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

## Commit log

2024-09-24 adjust leg for MG90S
    [leg_bottom.STL, leg_side.STL, leg_top.STL]
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2024-10-01 remove Fusion360 files
    [hexapod.f3d, joystick.f3d]
2024-10-13 #1 Correct schematic mistakes
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2024-12-17 pcb design
    [hexapod.kicad_pcb, hexapod.kicad_sch]
2024-12-18 gerber file for fab
    [hexapod-B_Cu.gbr, hexapod-B_Mask.gbr, hexapod-B_Paste.gbr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]
2024-12-29 remove old stl
    [accessory_cable_holder.STL, accessory_spacer_mg90s.STL, body_base.STL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]
2025-01-03 update Mini360 pad
    [hexapod.kicad_pcb]
2025-01-05 fix pcb
    [hexapod-B_Cu.gbr, hexapod-B_Mask.gbr, hexapod-B_Paste.gbr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]
2025-01-11 move pcb to another repo
    [hexapod-B_Cu.gbr, hexapod-B_Mask.gbr, hexapod-B_Paste.gbr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]
2025-02-22 add body models
    [body_base.STL, body_battery.STL, body_front_back.STL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]
2025-02-22 adding foot and joint model files
    [foot_bottom.STL, foot_ground.STL, foot_tip.STL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]
2025-02-22 add leg model files
    [accessory_cable_holder.STL, leg_bottom.STL, leg_side.STL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]
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2025-11-23 Refactor hexapod initialization and command parsing
    Improves code organization by extracting UDP command parsing into a dedicated function, adds helper for setting all servo positions, and introduces constants for hardware configuration. Enhances serial output for debugging, refines boot and motion execution logic, and replaces String usage with char buffers for efficiency. Also adds comments and minor delays for smoother operation and watchdog safety.
    [hexapod_esp32.ino]
2025-11-23 Delay boot sequence until WiFi client connects
    The boot-up motion now waits for a WiFi client to connect before executing. This ensures the hexapod only starts its boot sequence when a client is present, and allows OTA updates during the wait. If the WiFi AP is not started, the boot sequence is skipped with a warning.
    [hexapod_esp32.ino]
2025-11-24 Trigger boot sequence on WiFi client connect
    Replaces blocking wait for client connection with a WiFi event handler that triggers the boot sequence when a station connects to the AP. Adds flags to ensure the boot sequence runs only once and improves responsiveness during OTA mode.
    [hexapod_esp32.ino]
2025-11-24 Refactor motion command handling with unified config
    Introduced a MotionConfig struct and array to unify motion command mapping and LUT selection. Replaced repetitive if-else chains in loop() and parseCommand() with table-driven lookups, improving maintainability and scalability. Updated function documentation for clarity and conciseness.
    [hexapod_esp32.ino]
2025-11-24 Add detailed comments and structure to hexapod_esp32.ino
    Improved code readability by adding descriptive comments, section headers, and clarifying variable purposes throughout the hexapod_esp32.ino file. Enhanced documentation for motion configuration, har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
2025-11-24 Expand and update hexapod ESP32 README
    README now includes detailed setup instructions, hardware requirements, feature overview, UDP command reference, OTA update steps, troubleshooting, and guidance for adding custom motions. This improv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
2025-12-28 Update 3D body parts and images, remove obsolete files
    Added new 3D model files for body components and updated several existing STL and image files. Removed obsolete accessory and body part files, along with their corresponding images, to reflect the la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
    [accessory_cable_holder.STL, body.3mf, body_base.STL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]
2025-12-29 Add Bambu Studio 3MF files for body, foot, joint, and leg
    Renamed 'body.3mf' to 'bambu_studio_body.3mf' and added new 3MF files for foot, joint, and leg components, all intended for use with Bambu Studio.
    [bambu_studio_body.3mf, bambu_studio_foot.3mf, bambu_studio_joint.3mf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]
2025-12-29 Update 3D print parts list and hardware specs in README
    Revised the 3D-printed parts table to reflect updated part names, quantities, and images. Removed redundant print orientation notes and accessory section. Updated hardware specifications for screws a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
2025-12-29 Revise and expand README with detailed build instructions
    Enhanced the README with clearer feature descriptions, a comprehensive bill of materials, detailed assembly steps, and expanded software setup instructions for both ESP32 and Raspberry Pi Pico. Added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
2025-12-29 Update assembly_body.gif image
    Replaces the existing assembly_body.gif with a new version. This may reflect updated visual content or corrections to the image.
2025-12-29 Update assembly GIF images
    Replaced or modified assembly_foot.gif, assembly_joint.gif, assembly_leg.gif, and assembly_whole.gif with new versions to reflect updated visuals or corrections.
2025-12-29 Update calibration images
    Replaced calibration_1.jpg and calibration_2.jpg with new versions to reflect updated calibration data or improved image quality.
2025-12-29 Update servo reference and image in README
    Replaced the 21G servo with the MG92B servo in the parts list, updated the image accordingly, and removed the old servo image.
2025-12-29 Update assembly_whole.gif image
    Replaced the existing assembly_whole.gif with a new version. This may reflect updated visual content or corrections in the image.
2025-12-29 Revise and expand setup and usage instructions in README
    Updated the README to clarify and expand setup steps for both ESP32 and Raspberry Pi Pico, including detailed library requirements, board configuration, and WiFi/OTA instructions. Added explicit UDP 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
2025-12-29 Update switch type and image in README
    Changed 'Rocker Switch' to 'Toggle Switch' in the parts list, updated specifications, and replaced the switch image to match the new description.
2025-12-29 Update README formatting and instructions
    Removed print time estimate, improved formatting with spacing and code blocks, and clarified setup and usage instructions for better readability.
2025-12-29 Update servo tick conversion rate in README
    Corrected the servo angle-to-tick conversion guidance from '1° ≈ 10 ticks' to '0.44° ≈ 1 tick' for improved accuracy in calibration instructions.
2025-12-30 Update reference image captions in README
    Changed the captions for the reference images in the calibration section to improve clarity. 'Front View - Check coxa and femur alignment' is now 'Front View', and 'Side View - Check all three joints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
2025-12-30 Update PCB diagram images for ESP32 and Pico
    Refreshed both JPG and SVG files for ESP32 and Pico PCB diagrams. SVG files show updated Inkscape metadata and possible diagram adjustments.
2025-12-31 Fix right leg offset tick value in config
    Corrected the right_offset_ticks value for the first leg from -10 to 10 to address installation error compensation.
    [config.h]
2026-01-12 Update right leg offset ticks in config.h
    Adjusted the right_offset_ticks array to correct installation error values for the hexapod ESP32 configuration. Also updated the 3D print file for the Bambu Studio foot.
    [bambu_studio_foot.3mf]
2026-01-17 Reset leg offset ticks and enable posture calibration
    Set all left and right leg offset ticks to zero in config.h, effectively removing previous installation error corrections. Also, enabled the posture_calibration() call in setup() and commented out the main motion execution logic in loop(), likely for calibration or debugging purposes.
    [config.h, hexapod_esp32.ino]
2026-01-17 Update 3D body parts and add 18650 battery holder
    Added a new 18650 battery holder (2S2P) STL file. Updated several body, foot, joint, and leg STL files. Removed obsolete body_battery.STL and body_head.STL files to reflect design changes.
    [18650 battery holder 2S2P.stl, body_base.STL, body_battery.STL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]
2026-01-29 Add body_battery.STL 3D model file
    Added a new STL file for the body battery component in the 3D print/body directory.
    [body_battery.STL]
2026-02-01 Update 3D prints and adjust servo offsets
    Replace binary 3MF/STL assets for foot and body side, and update hexapod calibration offsets. In software/hexapod_esp32/config.h the left_offset_ticks and right_offset_ticks were changed from all zeros to calibrated values to correct installation misalignment ({ {15,10,15},{5,10,15},{-8,5,-5} } and { {0,0,-5},{-5,-10,-10},{-5,-10,-15} } respectively).
    [bambu_studio_foot.3mf, body_side.STL]
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2026-02-01 Add web calibration UI and EEPROM storage
    Introduce a web-based calibration interface and persistent EEPROM storage for servo offsets. Adds WebServer and EEPROM includes, EEPROM layout/constants and load/save helpers, and integrates EEPROM initialization into setup(). Implements a calibration web UI (HTML/JS) served at "/" and routes for entering/exiting calibration, getting/setting offsets, and saving offsets to EEPROM (also prints offsets to Serial for backup). Adds calibration_mode flag and skips motion execution while calibrating; calls posture_calibration() to apply offsets. Also integrates web_server handling into loop(), refactors formatting/brace style, and includes various minor cle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
    [hexapod_esp32.ino]
2026-02-01 Improve calibration UI and save behavior
    Update the web calibration page: add a visual reminder and CSS for saving offsets, clarify tick→degree conversion in the header, and shorten the main title. Rename the frontend handler from applyAndSaveOffsets() to saveOffsets(), update related button label and status messages to better instruct users to click Save Offsets, and simplify the server response to remove the Serial Monitor mention. These changes improve usability and clarity for servo offset calibration.
    [hexapod_esp32.ino]
2026-02-01 Update UI theme, layout tweaks and footer
    Revamp the web UI styles: replace cyan accents with purple tones (titles, buttons, borders, status), adjust button colors/hover, increase input width, tweak spacing (leg-grid gap, leg-column gap, joint-row layout), and add a footer with copyright info. Also minor CSS utility changes (.btn-small margin, input border color, margin-right) to improve alignment. Reformat web_server.on lambda handlers for calibration routes to multi-line style (no behavioral change).
    [hexapod_esp32.ino]
2026-02-01 Reduce servo delay and zero servo offsets
    Adjust config.h to speed up servo updates by changing DELAY_MS from 30 to 20. Also reset left_offset_ticks and right_offset_ticks to all zeros to remove previous calibration offsets and neutralize servo positions.
    [config.h]
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2026-03-15 Update hexapod gait LUTs and generator
    Adjust lookup tables for walking motions across multiple orientations (walk_0, walk_180, walk_r45, walk_r90, walk_r135) in software/hexapod_esp32/motion.h and the corresponding motion.h in software/path_tool. Numerous leg coordinate/servo values were changed to recalibrate stride, step height and rotation behavior (smoother transitions and improved foot clearance). Also update lut_generator.ipynb to reflect/regenerate the new LUT data.
2026-03-15 Add body_head.STL and update Bambu 3MF
    Add new 3d print/body/body_head.STL model and update the existing 3d print/bambu_studio_body.3mf project file (binary) to reflect the change. This adds the head part to the print assets and updates t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
    [bambu_studio_body.3mf, body_head.STL]
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2026-07-20 Add binary UDP protocol with failsafe
    Implement efficient binary UDP control packet format (magic byte 0xA5, command ID, sequence number) with automatic failsafe that triggers standby mode if no UDP packets received for >500ms. Add web calibration interface documentation and support for EEPROM-based servo offset storage. Maintain backwards compatibility with legacy string-based commands.
    [hexapod_esp32.ino]
2026-07-20 Remove v1 deprecation warning from README
    Remove the MG90S servo failure warning for Hexapod v1, adjust image widths and remove LEGO variant photos. Add TPU material recommendation for foot_tip component and clean up table formatting in assembly instructions.
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2026-07-26 Update hexapod designs and preview images
    Add new fence component to body assembly and update 3D print files and their corresponding preview images. This includes modifications to body battery, body top, and joint bottom components.
    [body_battery.STL, body_top.STL, fence.STL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]
2026-07-26 Update Bambu Studio 3MF model files
    Replace updated binary 3MF exports for the robot parts: bambu_studio_body.3mf, bambu_studio_foot.3mf, bambu_studio_joint.3mf, and bambu_studio_leg.3mf. These are regenerated/modified 3D model files (no source code changes).
    [bambu_studio_body.3mf, bambu_studio_foot.3mf, bambu_studio_joint.3mf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]
2026-07-26 Create 18650 battery holder 2S2P.3mf
    [18650 battery holder 2S2P.3mf]
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2026-07-26 Update assembly images
    Replace three assembly GIFs with updated versions: images/assembly_foot.gif, images/assembly_joint.gif, and images/assembly_leg.gif. These are binary updates to the assembly diagrams (visual improvements or corrections).
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2026-08-07 Add real-time pose streaming for hexapod
    Implement real-time 18-servo pose control via UDP, allowing direct servo position commands in addition to pre-programmed gaits. Adds two new binary packet types: 0xA6 for streaming raw servo positions (44 bytes) and 0xA7 for session control (enter/exit/relax/ping). Includes failsafe timeout (1s), per-joint slew-rate limiting to prevent servo damage, proper thread-safe state management, and servo position clamping. Motion commands (0xA5) continue to work and implicitly exit real-time mode. Suppress logging of high-frequency pose packets to avoid serial port saturation.
    [config.h, hexapod_esp32.ino]
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2026-09-13 Refresh ESP32 setup docs
    Updated the project and ESP32 documentation to match the current firmware and hardware layout. This includes the new default WiFi SSID, real-time UDP pose streaming details, corrected file references, expanded firmware file structure, OTA/calibration guidance, and refreshed links and asset references for the 3D-printed parts and board docs.
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2026-09-18 Update docs for Macaroon controller
    Refresh the hardware guide to match the newer Macaroon ESP32 controller board. This update changes the recommended parts list, notes the 8.4V servo requirement and switch sizing, adds the new connection diagrams, and points users to the board bundle instead of a separate battery-holder print file. It also removes the old 3D-printable battery holder assets that are no longer referenced.
    [18650 battery holder 2S2P.3mf, 18650 battery holder 2S2P.stl]
2026-09-18 Update 18650 battery holder link in README
    Replaced the local 3D-print file link for the 18650 battery holder with a direct product page URL (https://rookidroid.com/product/18650-battery-holder/) in README.md. The note about purchasing together with the Controller Board remains unchanged.
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2026-09-24 Consolidate nougat, mochi and macaroon into one branch
    The three robots lived on separate branches even though their firmware
    was byte-identical and the path tool differed only in its data. Fixes
    had to be copied between branches by hand, and nougat's path_tool.py
    was already missing the standup azimuth fix.
    The robots now share one tree, with per-robot data in folders:
    - robots/<name>/: README (build guide), 3d print/ and images/ from
    each branch, unchanged
    - software/hexapod_esp32: shared firmware. robot.h selects the robot
    (ROBOT_NOUGAT / ROBOT_MOCHI / ROBOT_MACAROON, also settable with
    -D). src/robots/<name>/ holds robot_config.h (APSSID, DELAY_MS)
    and the generated motion.h
    -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
    [body_base.STL, body_battery.3mf, body_battery.STL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]
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2026-09-30 ESP32 motion engine and NVS calibration
    This commit refactors the ESP32 firmware around a single tick-driven motion engine that handles LUT playback, real-time pose streaming, calibration posture, and relax/failsafe states without blocking the web UI or OTA. Calibration storage moves from EEPROM to NVS/flash with automatic migration of legacy values, and the calibration page now validates offsets and saves to flash. It also adds a GitHub Actions build matrix for ESP32 targets, updates robot LUT typing and selection, and removes the legacy Pico firmware.
    [calibration.ino, config.h, hexapod_esp32.ino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]
2026-09-30 Tune Nougat motion LUTs
    Updated the Nougat motion lookup tables for walking, turning, climbing, and rotation profiles. The changes refine joint angle offsets and motion timings across the LUTs to improve pose balance, smoother transitions, and corrected kinematic values.
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2026-10-02 Add browser drive controls and tabs
    This adds a single web UI for driving and calibrating the ESP32 hexapod. The page now has Drive and Calibrate tabs, hold-to-move controls with keyboard shortcuts, gait/body actions, and a speed slider. It also adds HTTP routes for motion and relax commands that match the UDP failsafe behavior. The README and comments were updated to document the new browser workflow and routes.
    [web_ui.ino]
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2026-10-03 Refine drive console layout and speed controls
    Reworked the drive deck console into a centered, compact panel with a dedicated speed gauge, grouped action buttons, and a visually improved range slider. The layout now uses a more flexible desktop column sizing and keeps the controls readable on smaller screens. The speed readout also updates the slider track fill so the interface reflects the active gait value more clearly.
2026-10-03 Fix Android touch capture issues
    This change avoids losing a pointer press when pointer capture fails and prevents Android Chrome's long-press gesture from interrupting pad input. The pad now tries to capture pointer events safely and cancels touchstart events when possible so the web UI keeps receiving pointermove/up events without triggering the browser context menu or selection buzz.
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2026-10-05 Rework hexapod logo body as a rotated hexagon
    Drop the red head plate, give the torso a hexagonal shell with a matching
    blue chest, and rotate the whole robot 45 degrees inside the badge.
    Regenerate the PNGs and sync the per-robot copies.
    Claude-Session: https://claude.ai/code/session_01RdmdoN2zQu445suiDmTTAs
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

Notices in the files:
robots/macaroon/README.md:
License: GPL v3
